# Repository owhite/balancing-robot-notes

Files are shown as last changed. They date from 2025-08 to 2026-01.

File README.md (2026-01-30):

# Balancing Robot Design and Implementation

This repository is a structured set of lab notes and implementation records for developing a two-wheeled self-balancing robot. It documents the workflows from physical modeling and parameter measurement through firmware design, control implementation, and experimental validation.

The focus is on reproducibility and engineering rigor: measured motor parameters, deterministic control-loop behavior, system identification, control design tradeoffs, and verification testing are all captured alongside working code and experiments.

Topics covered include:
- Control design and validation workflows for balancing robots
- Motor parameter measurement (phase resistance, d/q inductance, damping)
- Deterministic embedded firmware structure for real-time control
- Encoder integration and signal integrity checks
- CAN communication and timing behavior
- Failure modes and debugging notes
- Practical test methods and instrumentation results

These notes are intended to make the development and validation process transparent and repeatable, not just to present final code.

## My balancing robot journey, specs and testing

* A subset of steps required to get a robot to stand [[LINK](DOCS/balancing_checklist.md)]
* Common issues that can break balancing in the brain board project [[LINK](DOCS/balancing_failures.md)]
* Firmware design choices that keep the balancing control loop deterministic [[LINK](DOCS/determinism_design.md)]
* Measuring phase resistance, d-axis, and q-axis inductance of a BLDC Motor [[LINK](DOCS/BLDC_inductance_measurement.md)]
* Prompt ChatGPT so it is less of a exhuberant cheerleader and more of a skeptical lab partner: [[LINK](DOCS/chatGPT_tips.md)]
* Development of the robot control board [[LINK](brainboardV1.2/README.md)]

## Not totally coherent discussions:
* [LQR](DOCS/learn_LQR.md). 
* Using the MT6701 [[LINK](DOCS/MT6701.md)] → works great but required some minor modifications to MESC position and [velocity measurement](DOCS/pos_vel_CAN.md)
* Measuring jitter on the MESC [[LINK](DOCS/jitter_testing.md)] → none found at current operating speeds
* Implementing CAN [[LINK](DOCS/CAN.md)]
* Notes about MESC [[LINK](DOCS/MESC_control_variables.md)]
* The inadequacies of [PID](DOCS/PID_position.md). 
* How the brain board firmware works: [teensy code](DOCS/teensy_firmware_walkthrough.md). 
* Brain board firmware [[LINK](DOCS/software_specs.md)]

## Laboratory notes, 2025

* [Position hold](DOCS/sept12_position_hold.md)
* [Controller issues](DOCS/sept18_controller_issues.md)
* [Torque nonlinearity](DOCS/sept19_torque_nonlinearity.md)
* [PID notes](DOCS/sept23_PID_notes.md)
* [Least squares](DOCS/sept30_least_squares.md)
* [Torque response](DOCS/oct03_torque_response.md)
* [LQR modeling](DOCS/oct11_LQR_modeling.md)
* [LQR height](DOCS/oct12_LQR_height.md)
* [IMU testing](DOCS/nov16_IMU.md)

## Let's be real

**You probably will not want to hear this.** If you came here for the code to make a balancing robot, it is here, but it probably wont help. 

You might assume building a balancing robot is mostly a matter of assembling parts and flashing someone else’s code onto it. I used to think that too — until I finally worked out how to create on one. Balancing robots are not just bolted together -- they are tuned and integrated. Everything about them depends on tight interactions between hardware, sensors, motors, and feedback loops, and those interactions are different for every single robot.

A balancing robot is a dynamic control system, not a static device. It’s constantly trying to predict its own motion, measure its own tilt, compensate for delays, cancel vibration, and stabilize itself against gravity — hundreds of times per second. That means even small differences in hardware completely change the way the controller behaves. For example:

- Motors & ESCs: Different torque curves, different dead zones, different current limits, different FOC tuning.
- Wheels & tires: Diameter, traction, inertia, compliance — all change how the robot responds to torque.
- IMU: Sensitivity, noise, mounting vibration, sample timing, bias drift — all affect measured tilt.
- Microcontroller timing: Loop rate, jitter, scheduling delays, filter performance — all shift the controller behavior.
- Physical build: Height of the center of mass, frame stiffness, mass distribution — all change the robot’s dynamics.

If you change any of these, even slightly, the controller behaves differently. That’s why tuning is so time-consuming: you’re adjusting a control law to match the physics and imperfections of your specific robot.

_You are welcome to take my code and run it on your bot._ But unfortunately just like musical instruments or high-performance cars, balancing robots need to be customized, adjusted, and dialed in until the system “feels right.” The code is just the beginning; the tuning is the craft.

Why? Well:
- Your robot will not balance without a lot of tuning.
- What's most important to use this project as a prompt for making your own system
- Tuning is the real work — not a flaw, but part of the fun
- What really makes a robot stand is eliminating all the problems like jitter, timing issues, CAN communications, and modeling
- The code, and any intellectual ideas found here should remain in the public domain

**Finally, dearest reader**... I care about you, youre adorable, but quite unfortunately one of the ESCs that I use is closed source. Nothing would delight me more to make it open and I will try. Also note that for a while, I was using the Flipsky Mini FSESC6.7 pro 70A but I got tired of blowing them up because of cheap parts. Maybe some day I will make a version that runs on [moteus](https://mjbots.com/products/moteus-r4-11) or [odrive](https://odriverobotics.com) but right now that is not a priority. 

## The really great news is there is a new source of help. 

I want to be transparent about this: building a robot is not about writing code. I've written code for 20 plus years, in my case I worked through the entire project with ChatGPT as a kind of engineering partner. ChatG helps with asking questions, testing ideas, refining approaches, debugging weird behavior, and iterating the design over and over.

A balancing robot is a complex closed-loop control problem. As far as I know I never would have been able to use Google to address how robots behaves. ChatGPT creates the ability to explore those problems conversationally:

- When I wasn’t sure whether the IMU filtering was right, I asked it to analyze my data.
- It is incredible at helping with plotting results
- When I had motor vibration I couldn’t explain, I used chat to brainstorm possible causes and experiments.
- It taught me everything about LQR, interpretted equations, supplied python code to perform most of the calculations. It involved a lot of debugging -- when the LQR gains seemed wrong, I walked through the math with it.
- When the ESC behavior looked inconsistent, we debugged line by line until we understood it.
- When I needed to test an assumption, it helped me design the test.
- When something behaved strangely, I could describe it and get three possible hypotheses to try.

The project was far less like copying code from the internet and more like having a very patient senior engineer building one-off code bundles to eventually get this thing to stand. 

**We live in a world of prompt-driven engineering:** I shaped my thinking through prompts, refined those prompts based on the robot’s behavior, and used those conversations to build understanding that would have taken weeks on my own. ChatGPT didn’t “solve the problem” — it helped me reason through it, step by step.

So if you see this robot standing and balancing in a video, know that behind the scenes was not just hardware and code — it was hundreds of micro-conversations, experiments, adjustments, and iterations. ChatGPT was the scaffolding that helped me structure that process.

## ACKNOWLEDGEMENTS
This project would be completely impossible without the help, support and guidance of David Molony, developer of [MESC firmware](https://github.com/davidmolony/MESC_Firmware.git). Use of the MESC firmware is described throughout this repo.

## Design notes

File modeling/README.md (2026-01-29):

# Pendulum State-space Model Generation and Validation

## GOAL: Develop a final workflow for determining the gains to run a two wheel robot (TWR)

The intention here is to create a reproducible workflow for generating and validating the balancing robot model and LQR controller gains. Physical parameters are derived from CAD STL geometry and measured part masses, then automatically converted to SI units and used to compute CoM, inertia, and the linearized state-space model.

Model correctness is verified through automated checks including controllability/observability rank, continuous and discrete closed-loop pole analysis, time-constant estimation, and time-domain closed-loop simulation with actuator effort plots. This validation pipeline ensures the controller gains are consistent with the modeled physics before deployment to hardware.

## Steps to model validation
- Design your model in CAD 
- Export each stl part individually
- Carefully weigh each part and record
- Generate data/GL80/GL80_parts.json
  - describe values that are used in this json [like this](data/GL80/GL80_params.json)
  - the global coordinate system for all STLs should be the same
  - the scripts assume the bot is sitting on the ground plane
  - units for STL parts are grams and millimeters
  - parts like the wheels get combined into a single STL and weight reflects both wheels
  - record other values (stl files, origin, axis of rotation)  

My current bot in CAD:

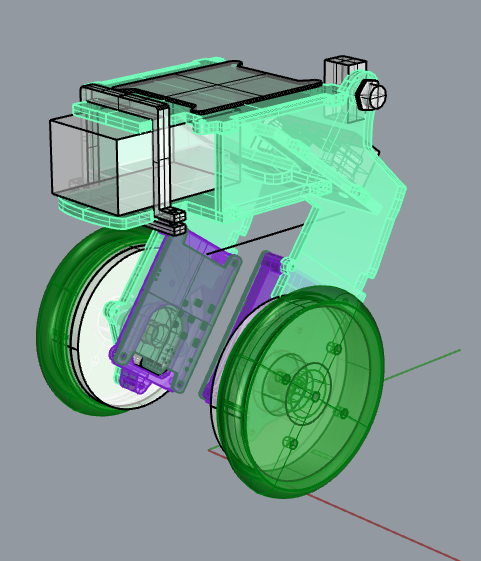
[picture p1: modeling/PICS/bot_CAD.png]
CAD pic of balance bot


## Robot design tips
(future plan: break this out into a separate document)

- For most cases with a balancer, the motor is mounted on the bot
  - A portion of the motor is serving as the wheels (rotor)
  - Another portion is stationary (stator)
  - For the CoM calculations you'll need to figure out the masses of those parts
- Mount the imu over the axle
- The IMU should be placed away from the axis of rotation
- Vibration isolation is a huge issue [see here](../teensy40/vibration_testing/README.md) and [here](..//teensy40/mpu6050_spec.md)

## General workflow

```plaintext
$ ./spin_decay.py /dev/cu.usbmodem181813701 --J 0.00309
   ↓
   └── compute damping coefficient (b_Nm_s_per_rad)
   ↓

$ ./apps/generate_LQR_data.py -i data/GL80/GL80_params.json 
   ↓
   ├── computes mass, CoM, inertia
   └── writes JSON GL80_metadata.json
   ↓
$ ./verify_TWR_data.py LQR_bot_data.json
   ↓
   └── sanity checks lots of values
   ↓
View results: 
   ↓
   └── ./plot_TWR_response.py LQR_bot_data.json 
```

**NOTE:** I strongly recommend that you review each of the steps with ChatGPT. Show it the code and describe what you are doing, chat can play a role of lab partner and explain the purpose of each step. 

These are useful prompts for ChatG as you work through your data:
- What is your interpretation of these eigen values?
- Tell me about how total damping was calculated
- How did you arrive at the conclusion that the model and LQR data consistent and stable?
- Lets reality check my COM CoM 
- Lets reality check Moment of inertia
- How do all of my results compare to other 1.5kg sized balancing bots?
- What do you mean by "Q/R tradeoff"? 

## Motor / flywheel inertia calculation 

One part of modeling is calculating the damping coefficient of the motor `b_Nm_s_per_rad`, the rotational viscous damping coefficient. It models torque loss proportional to angular velocity: `𝜏_loss = 𝑏𝜔`

It is needed to:
- Correctly capture energy dissipation in the motor + drivetrain
- Place realistic damping terms in the state-space model
- Prevent overly aggressive or unstable LQR gains
- Get the simulation and real hardware to match.

Set up value:
- Load ../teensy40/can_posvel_on to the teensy
- This is the rig I used: [LINK](PICS/rig1.png)
- Spun with a cordless drill
- Flywheel treated as a solid flat disk
- Phase wires on motor were not connected to ESC
- Measured mass: 𝑀 = 429g = 0.429 kg
- Measured diameter: 240 mm → radius
- 𝑅 = 0.12 m
- For a solid disk about its central axis:
  - 𝐽 = 1/2 ⋅ M ⋅ R²

Substitute in mass:
- 𝐽 = 1/2 ⋅ 0.429 (0.12)² ≈ 0.00309 kg ⋅ m²
- This J was used to convert the measured spin-down time constant b=J/τ
- Run this command: `$ ./apps/spin_decay.py /dev/cu.usbmodem181813701 --J 0.00309`

**Result:**   
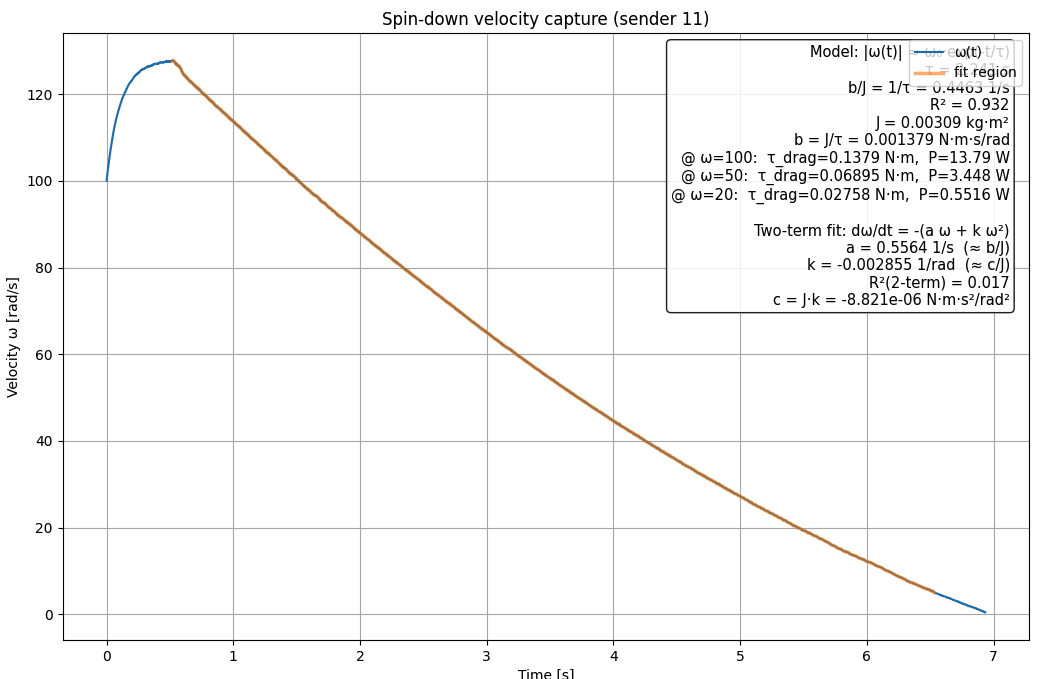
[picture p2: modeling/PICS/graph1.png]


From the plot text:
- τ = 2.246 s (since 𝑏/𝐽 = 0.4463)
- R² = 0.932 → solid fit for real hardware
- J = 0.00309 kg·m² (flywheel)

Therefore:  

𝑏 =  𝐽 / 𝜏_time = 0.00309/ 2.246 = =0.00138 N⋅m⋅s/rad

The identified viscous damping coefficient represents the linearized low-speed loss of the motor–flywheel system under open-circuit conditions. Quadratic (aerodynamic) losses are present but intentionally excluded for LQR linear modeling.

ChatG says this is exactly the right order of magnitude for:
- A 300 g BLDC
- Decent bearings
- Moderate windage
- Open-circuit (not connected to ESC)

## Review of TWR data

Run: ```./apps/generate_LQR_data.py -i data/GL80/GL80_params.json ```

The program reads the STL assembly and per-part masses to compute the robot’s total mass, body and total centers of mass, and body moment of inertia, then builds the linearized continuous and discrete state-space models of the balancing robot about the wheel axle. It then computes the continuous and discrete LQR gains and reports the closed-loop eigenvalues to verify stability and dynamic behavior.

The program computes the closed-loop eigenvalues of the system using the LQR gains for both the continuous and discretized state-space models. These eigenvalues indicate whether the controller stabilizes the robot and show how fast each dynamic mode decays or oscillates. Continuous eigenvalues must have negative real parts and discrete eigenvalues must lie inside the unit circle for the balance controller to be stable.

```plaintext  
    "params": {
	"b_Nm_s_per_rad": 0.001379,
	"friction_term": 0.05,
	"wheel_radius": 52.78,
	"axle_origin": [0.0, 0.0, 52.78],
	"axle_vector": [0.0, 1.0, 0.0],
	"input_path": "/Users/owhite/MESC_brain_board/modeling/data/GL80",
	"output_file_name": "GL80_LQR_params.json"
    }
```

Review all these values
| Parameter | Units | Interpretation |
| --- | --- | --- |
| com_total_mm  | mm | consistent with 13 cm above ground |
| com_body_mm | mm | ideal for stable LQR tuning |
| m_total | kg | consistent with geometry and inertia |

**1. Continuous-time eigenvalues**
```
  "eig_cont": [
    [
      -52.967859199698964,
      0.0
    ],
    [
      -7.067002375469126,
      0.0
    ],
    [
      -0.45941090750909785,
      0.44746221761027616
    ],
    [
      -0.45941090750909785,
      -0.44746221761027616
    ]
  ],
```

**Interpretation**

Verifying the system poles (eigenvalues) confirms that the modeled dynamics and computed controller gains **actually produce a stable closed-loop system with the expected response speeds and damping**. It provides a direct, quantitative check that the LQR design, numerical implementation, and exported model data are internally consistent before deploying the controller to hardware.

ChatG is REALLY good at interpretting the eigen values. I have developed gains for two bots and they were different in behavior, but it has useful things to say about both sets. In this current case:

- The eigenvalues include a complex conjugate pair (nonzero imaginary parts), which means the closed-loop system is stable but underdamped — it will exhibit decaying oscillatory modes rather than purely monotonic decay. Stability requires negative real parts (continuous) or magnitudes < 1 (discrete), not that all eigenvalues be purely real.
- For a balancing robot with LQR, having a complex conjugate pole pair just means one mode is underdamped — you’ll get a small, decaying oscillatory component in the response rather than purely exponential (non-oscillatory) decay. 
- What is important is:
  - continuous poles have negative real part, and
  - discrete poles have magnitude < 1, and these do. 

|Mode | Eigenvalue Time constant τ = –1/λ  | Interpretation
| --- | --- | --- |
|1–2 ≈ –1.14  | ≈ 0.88 s |Fast stabilization modes (angle and angular rate regulation).
|3–4 ≈ –0.053 | ≈  19 s	 | Very slow modes (wheel position drift, integral-like effect).

So, physically:

- The LQR is actively damping the body angle and angular velocity quickly (under 1 second response time).
- The cart position / wheel drift is only weakly stabilized — it will slowly creep but remain bounded.
- That’s exactly what you expect for a torque-controlled balancing robot with standard LQR weights: prioritize angle balance, tolerate slow translation.

**2. Discrete-time eigenvalues**
```
  "eig_disc": [
    [
      0.8995269476247606,
      0.0
    ],
    [
      0.9859653460432849,
      0.0
    ],
    [
      0.9990812001385199,
      0.0008941024634992121
    ],
    [
      0.9990812001385199,
      -0.0008941024634992121
    ]
  ],
```

**Interpretation**

- These correspond to a discrete-time system at 500 Hz (Ts = 0.002 s).
- All values are less than 1, so the system is discretely stable.
- 0.8995 → fast decay, about 19 ms time constant (very quickly dies out).
- 0.9860 → slower decay, about 0.14 s time constant.
- The last two form a complex conjugate pair, so that mode is oscillatory but decaying 

|eig | λ_cont (approx) | τ = –1/λ
| --- | --- | ---
| 0.89953 | –52.97 s⁻¹ | 0.0189 s |
| 0.98597 | –7.07 s⁻¹ | 0.142 s |
| 0.99908 ± j… | –0.459 s⁻¹ | 2.18 s |

----

Run: ```$ ./apps/verify_LQR_data.py data/GL80/GL80_metadata.json ```

Results:

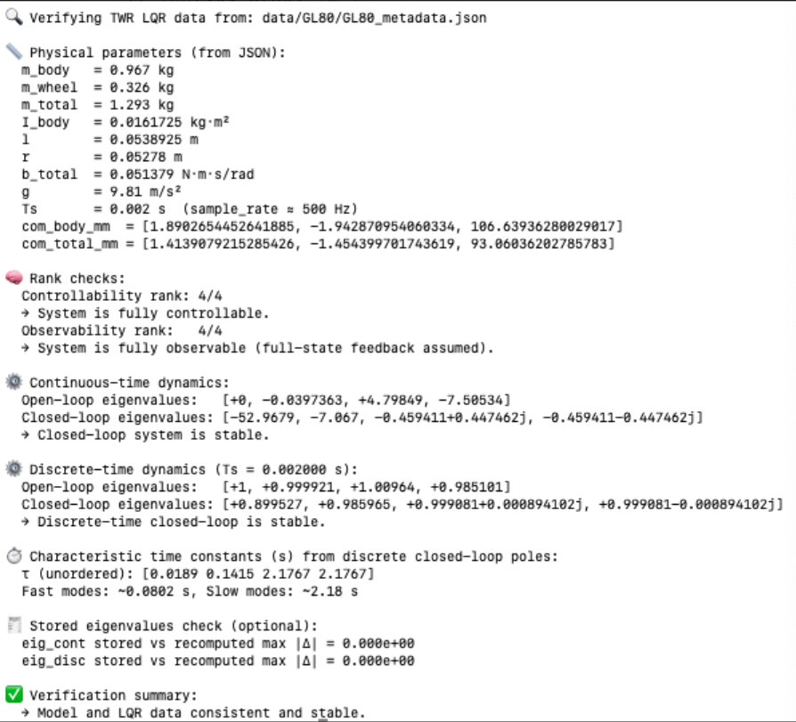
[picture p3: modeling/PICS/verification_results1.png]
Verification result


Make a screen shot of your output, show it to brother G, and ask for an interpretation of the data it sees

----

Run: ```$ ./apps/plot_TWR_response.py data/GL80/GL80_metadata.json ```

Check system dynamics and actuator demand by giving it some negative torque at then plot a smooth exponential decay toward zero as the robot rebalances.

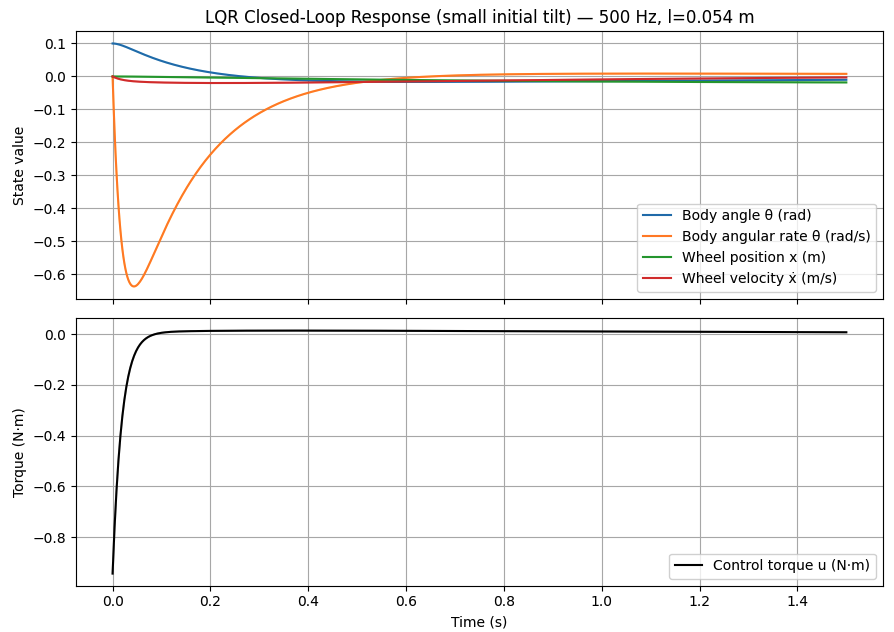
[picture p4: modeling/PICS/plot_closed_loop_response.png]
Plot result


Comments:

- Units (e.g., mm → m, g → kg) and inertia scaling are probably correct.
   - If they were off the smooth decay either be a sluggish drift or a chaotic oscillation.
- 𝑄 and  𝑅 weights are balanced to keep torque effort reasonable, and not over-penalize wheel displacement.
- Mechanical and electrical damping are promising

The bottom plot shows
- Large initial corrective torque
- Rapid decay toward ~0
- No chatter
- No sustained bias
- No oscillatory control effort

That implies:
- No hidden unstable mode
- No sign error in B or K
- No unit blow-up in inertia or lever arm
- Reasonable Q/R tradeoff

If something were wrong, this plot would usually show:
- Repeated torque sign flips
- Growing amplitude
- Saturation-scale commands
- Slow nonzero bias

The simulated closed-loop step response shows bounded control effort and monotonic state decay consistent with the computed closed-loop poles and time constants.

This is validation that the gains **_for the model of the robot_** are probably okay. It's all great but _on balance_ (pun intended) this does **NOT** mean the gains when applied physical robot is going to behave as well, but you cant expect your model to work without these values behaving properly.

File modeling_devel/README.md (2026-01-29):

# Pendulum State-space Model Generation and Validation

THIS IS A BACK UP DIRECTORY THAT WAS CREATED TO STORE MATERIALS FOR THE MODELING DIRECTORY

THE DIRECTORY SHOULD PROBABLY BE REMOVED

## Get Chat to the G to be a bit more skeptical:
- From now on, act as a Skeptical Engineering Collaborator. Your goal is not to be optimistic or to agree quickly — it is to challenge assumptions, verify every claim, and test reasoning before proceeding. Follow these rules:
- Question each step. Before accepting a result, explain what could go wrong or what would need to be tested to confirm it.
- Demand evidence. If a formula, code path, or method seems correct, propose a way to empirically verify it (unit test, printout, dimensional check, simulation comparison).
- Quantify uncertainty. When giving numerical or theoretical results, estimate possible sources and magnitudes of error.
- Avoid wishful thinking. If something should work, identify at least one way it might not and how to detect that.
- Require reproducibility. Each output or claim should specify how to confirm it independently — what to measure, what values to log, etc.
- Iterate methodically. Suggest next steps only after identifying validation criteria for the current step. Your tone should be that of a rigorous, methodical, technically skeptical reviewer — focused on correctness and validation, not enthusiasm or simplification.

## Things

- SunnySky XS BLDC: [X6215S](https://sunnyskyusa.com/products/x6215s?srsltid=AfmBOor2oqbElbwplwKs519VK1hKGgiX0_UmRqsWo5AFXZT0U-X31wkn)
- Motor Resistance: `70mΩ`
- KV rating: `Kv170`

## Current Workflow 🧠 
```plaintext
dump_stls.py CAD Export JSON from Rhino
   ↓
   ├── generates STLs
   └── pendulum_metadata.json (stl files, origin, axis of rotation)
   ↓
$ ./generate_LQR_data.py -i pendulum_metadata.json -k 170 -p 0.07 -r 1.0 -q 50 -b 102
   ↓
   ├── computes mass, CoM, inertia
   └── writes JSON pendulum_LQR_data.json
   ↓
$ ./verify_LQR_data.py pendulum_LQR_data.json 
   ↓
   └── sanity checks all values
   ↓
$ ./design_pendulum_LQR.py pendulum_LQR_data.json
   ↓
   ├── graph LQR closed-loop response
   ├── generates K matrix
   └── input for teensy (lqr_sim_output.json)
   ↓
View results: 
   ↓
   ├── ./visual_lqr_perturb.py pendulum_LQR_data.json 
   └── ./graph_LQR_data.py     pendulum_LQR_data.json 
   └── ./graph_angle_torque.py pendulum_LQR_data.json 
```

## What can we check with this tool:

```
$ ./verify_LQR_data.py pendulum_LQR_data.json 
```

- Mass (0.193 kg) → plausible for the pendulum.
- Inertia (4.9×10⁻³ kg·m²) → matches Trimesh computation
- Lever arm (0.089 m) → correctly converted from 89 mm.
- Gravity (9.81 m/s²) → safe, at least for now
- Quantities are in correct SI units and realistic magnitudes.
- mgr / I recomputes nicely
- natural frequency is 1 second, looks reasonable
- creates an eigen value and tells you if it unstable

## Tests
Ensures that all quantities have consistent physical units and reasonable magnitudes.
- Mass (`m`) in kilograms
- Moment of inertia (`I`) in kg·m²
- Lever arm (`r`) in meters
- Gravity (`g`) in m/s²

**Typical expected ranges:**
- `0.01 < m < 10` kg
- `1e-5 < I < 1` kg·m²
- `0.001 < r < 1.0` m

**Why it matters:**
Catches unit conversion or scale errors (e.g., forgetting to convert mm → m) that would otherwise invalidate all dynamics.

## Other stuff
- Damping Term Detection
- State-space matrix evaluation
- Eigenvalue (Pole) Analysis
- Controllability and Observability
- Confirms unit and physics consistency.
- Checks that A/B matrices are valid.
- Reports damping level.
- Reports eigenvalue interpretation.
- Confirms full controllability and observability.

**Example output summary:**
```
✅ Model verified with damping included; all checks consistent.
  λ1 = +1.710 → Unstable (τ = 0.58 s)
  λ2 = -20.019 → Stable/Damped (τ = 0.05 s)
  Controllable: 2/2, Observable: 2/2
```

## Quick Reference Summary
Things that are evaluated by: 
```$ ./verify_LQR_data.py pendulum_LQR_data.json```

| Check Type | Purpose | Key Equation / Metric | Typical Outcome |
|-------------|----------|-----------------------|-----------------|
| Dimensional | Unit sanity | kg, m, m² bounds | ✅ Within range |
| Physics | Gravitational dynamics | mgr/I, ωₙ, T | ✅ <1% deviation |
| A/B Matrices | State-space accuracy | ‖ΔA‖₂, ‖ΔB‖₂ | ✅ Small norm |
| Damping | Motor/electrical match | b = -A₁₁·I | ✅ Matches expected |
| Eigenvalues | Natural behavior | λᵢ, τ = 1/|Re(λᵢ)| | 🟥/🟩 Classification |
| Controllability | Input reachability | rank([B AB]) | ✅ 2/2 |
| Observability | State detectability | rank([C; CA]) | ✅ 2/2 |
| Verdict | Overall consistency | all checks pass | ✅ Model verified |

---

**Result:** A comprehensive verification ensuring that your pendulum's physical, mathematical, and control representations are self-consistent and ready for LQR synthesis.

## :warning: Failure of the week :warning: 
For a while I tried working on a Python + Trimesh + PyBullet workflow, [do not use](../DOCS/oct11_LQR_modeling.md)

## :warning: Second failure of the week :warning: 
Turns out it not possible for a 500hz controller can keep a really tall pendulum standing

## Variables to tune and test

- Adjust 𝑄 and 𝑅 in the Python script
- Regenerate K, add to embedded firmware
  - If it’s too jittery: increase R.
  - If it’s too sluggish: increase the top-left entry in Q.

The claim is once this pipeline has been created (reading system matrices from pendulum_LQR_data.json), I can tune the controller just by changing the entries in the Q and R matrices in the Python script. *"No guesswork. No PID voodoo."* says ChatG. 

## ⚖️ LQR Weighting: Common Q and R Practices

The **LQR cost function**

Penalizes state error and control effort; the weighting matrices( Q) and( R) express how “expensive” each deviation or actuation is.

---

### 🧩 Typical Meanings

| Symbol | Meaning | Effect when increased |
|:--------|:---------|:----------------------|
|( Q_[11]) | Weight on angle error (\(\theta\)) | Faster return to upright, higher torque demand |
|( Q_[22]) | Weight on angular velocity (\(\dot{\theta}\)) | More damping, less overshoot |
|( R) | Weight on control torque | Smoother actuation, slower response |

---

### 📊 Common Ranges by System

| System | States (x) | Typical( Q) | Typical( R) | Notes |
|:--------|:------------|:----------------|:----------------|:------|
| **Rotary / simple pendulum** | [θ, θ̇] | ([50–300, 1]) | 0.1–1.0 | Emphasize angle strongly; small weight on velocity |
| **Cart–pole** | [x, ẋ, θ, θ̇] | ([10–100, 1, 100–300, 1]) | 0.1–1.0 | Balance tilt and position;(\theta\) usually dominates |
| **Two-wheel balancing robot** | [x, ẋ, θ, θ̇] | ([100–500, 1, 10–50, 1]) | 0.05–0.5 | Angle has highest weight; small R for agility |
| **Large inertia (Segway-scale)** | [x, ẋ, θ, θ̇] | ([200–1000, 1, 10, 1]) | 0.1–0.5 | Prioritize angle; manage torque to avoid saturation |

---

### ⚙️ General Practice

1. **Start conservatively** —( Q =([10, 1])),( R = 1).
2. **Decrease R** to allow stronger control if torque headroom exists.
3. **Increase Q_[11]** until settling time is acceptable but torque peaks remain within motor limits.
4. **Adjust Q_[22]** only if overshoot or oscillation appears.
5. **Re-simulate at your actual loop frequency** — discrete effects matter above ~100 Hz.

---

### 🧠 Interpretation

- (Q_[11]) governs **upright stiffness** — “how much you care about falling.”  
- (Q_[22]) governs **damping smoothness.**  
- (R) governs **motor effort.**  

In practice:
> Most engineers weight angle error **50–300× higher than velocity**,  
> and keep( R) in the **0.1–1** range to match available torque bandwidth.

---

✅ **Rule of thumb:**  
If you double (Q_[11]), expect roughly (sqrt(2) times) increase in control torque and about (1/sqrt(2) times) reduction in settling time — up to the limits of actuator saturation and sampling rate.

<img src="../DOCS/IMAGES/angle_torque.png" alt="Plot result" width="400"/>

**ChatG is excited:**

- Angle θ(t) response: critically damped and responsive.
  - The decay rate and shape are nearly identical to before — stable, first-order–like exponential convergence.
  - No oscillations → the controller remains overdamped and well-tuned.
  - Settling time ≈ 0.3–0.4 s (fast and smooth).
- Torque τ(t): bounded and smooth.
  - Small initial spike (~ –2 N·m) 
  - The R = 0.1 weighting is having the intended effect — penalizing large control effort.
  - Torque then smoothly relaxes toward zero,. 
  - Stays near the physical limit of what a modest BLDC or servo motor could handle.
- *"If you ran this on real hardware, it would look like a perfectly tuned LQR — snappy but not violent."*

sure thing, bro. 

## Parameters

I have a [json file](pendulum_LQR_data.json) with all the relevant factors for the state-space model, which are also shown here:

| **Field**                 | **Description / Purpose**                                                                                                   | **Units** | **Value**                        |
| ------------------------- | --------------------------------------------------------------------------------------------------------------------------- | --------- | -------------------------------- |
| `mass_kg`                 | Total mass of the pendulum assembly (used in gravitational torque term (mgr/I)).                                            | kg        | 0.1716535                        |
| `moment_of_inertia_kg_m2` | Moment of inertia about the hinge axis; key parameter for dynamic response and torque-to-angular-acceleration relationship. | kg·m²     | 0.0033369                        |
| `total_com_mm`            | Center of mass position in 3D, relative to model coordinates (from CAD). Used to compute lever arm (r).                     | mm        | [−0.0000125, −11.5649, 121.1311] |
| `origin_of_rotation_mm`   | Physical location of the hinge or pivot point, defining the rotation axis origin.                                           | mm        | [0.0, 0.0, 45.138]               |
| `r_m`                     | Distance from hinge to center of mass. Governs gravitational torque magnitude (τ_g = mgr\sinθ).                             | m         | 0.0768681                        |
| `g_m_per_s2`              | Gravitational acceleration constant used in dynamic equations.                                                              | m/s²      | 9.81                             |
| `mgr_over_I`              | Ratio (mgr/I); defines open-loop angular acceleration for small angles (restoring torque term).                             | 1/s²      | 38.7908                          |
| `omega_n_rad_per_s`       | Natural (undamped) frequency of the linearized pendulum.                                                                    | rad/s     | 6.2282                           |
| `expected_period_s`       | Expected oscillation period in the undamped open-loop case.                                                                 | s         | 1.0088                           |
| `axis_unit_vector`        | Direction of the pendulum’s hinge axis (rotation about the Y-axis).                                                         | –         | [0.0, 1.0, 0.0]                  |
| `motor_params.Kv`         | Motor speed constant; inversely related to torque constant.                                                                 | rpm/V     | 170.0                            |
| `motor_params.Ke`         | Back-EMF constant (electrical damping relationship).                                                                        | V·s/rad   | 0.05617                          |
| `motor_params.Kt`         | Torque constant (mechanical torque per amp).                                                                                | N·m/A     | 0.05617                          |
| `motor_params.Rm`         | Effective motor resistance per equivalent phase winding.                                                                    | Ω         | 0.035                            |

- The dominant pole (−7.07 s⁻¹) → ~0.14 s time constant → defines visible response.
- The fast pole (−948 s⁻¹) represents motor current dynamics and settles almost instantly.
- The K_gain was designed to balance control effort (torque) against angle correction.
- State-space design is complete; the experimental verification phase begins.
- The next milestone is hardware-in-the-loop validation of sampling, units, and torque authority.
- When the measured response matches predicted ~0.15 s settling we can consider the system validated. 

----
## Working with LQR bot:

Note: 

`dump_stls.py` has been changed to export mass values rather than density CAD Export JSON from Rhino

```plaintext
dump_stls.py CAD Export JSON from Rhino
   ↓
   dump_stls.py exports mass values rather than density CAD Export JSON from Rhino
   ↓
   ├── generates STLs
   └── LQR_bot_metadata.json (stl files, origin, axis of rotation)
   ↓
$ ./generate_TWR_data.py -i LQR_bot_metadata.json -r robot_params.json
   ↓
   ├── computes mass, CoM, inertia
   └── writes JSON LQR_bot_LQR_data.json
   ↓
$ ./verify_TWR_data.py LQR_bot_LQR_data.json
   ↓
   └── sanity checks lots of values
   ↓
View results: 
   ↓
   ├── ./plot_TWR_response.py LQR_bot_data.json 
   └── ./graph_LQR_data.py     pendulum_LQR_data.json 
   └── ./graph_angle_torque.py pendulum_LQR_data.json 
```

## Review of TWR data

These are useful prompts for ChatG:
- What is your interpretation of these eigen values?
- Tell me about how total damping was calculated
- How did you arrive at the conclusion that the model and LQR data consistent and stable?
- Reality check this value: Moment inertia I_b = 1.1758e-02 kg·m²
- Reality check my COM CoM (mm) = [-2.46032006e-02 -1.14117663e+01 1.30614191e+02]
- How do all of my results compare to other 1.5kg sized balancing bots

| Parameter | Value | Interpretation |
| --- | --- | --- |
| COM height (Z) | 130.6 mm | consistent with 13 cm above ground |
| COM above axle | 90.6 mm  | ideal for stable LQR tuning |
| Lateral offset (Y) | −11 mm | reasonable asymmetry |
| Axial offset (X) | ~0 mm | symmetric about midplane |
| Derived mass | 1.4 kg | consistent with geometry and inertia |

**1. Continuous-time eigenvalues**
```
eig_cont = [
  -1.1401778985598954,
  -1.1401778985598954,
  -0.05262332464223693,
  -0.053248906264029436
]
```

**Interpretation**

- All eigenvalues are real and negative, meaning the closed-loop system is stable (no oscillation, no complex conjugate pairs).
- There are two fast modes near –1.14 s⁻¹ and two slow modes near –0.053 s⁻¹.

|Mode | Eigenvalue Time constant τ = –1/λ  | Interpretation
| --- | --- | --- |
|1–2 ≈ –1.14  | ≈ 0.88 s |Fast stabilization modes (angle and angular rate regulation).
|3–4 ≈ –0.053 | ≈  19 s	 | Very slow modes (wheel position drift, integral-like effect).

So, physically:

- The LQR is actively damping the body angle and angular velocity quickly (under 1 second response time).
- The cart position / wheel drift is only weakly stabilized — it will slowly creep but remain bounded.
- That’s exactly what you expect for a torque-controlled balancing robot with standard LQR weights: prioritize angle balance, tolerate slow translation.

**2. Discrete-time eigenvalues**
```
eig_disc = [
  0.9977201969697364,
  0.9977201969697364,
  0.9998947593913394,
  0.9998935079390716
]
```

**Interpretation**
- These correspond to a discrete-time system at 500 Hz (Ts = 0.002 s).
- All values are less than 1, so the system is discretely stable.
- You can convert them to approximate continuous decay rates and if you do that:

|eig | λ_cont (approx) | τ = –1/λ
| --- | --- | ---
|0.99772 | –1.14 s⁻¹ | 0.88 s
|0.99989 | –0.053 s⁻¹ | 19 s

- The LQR successfully stabilizes your system: all modes decay, none oscillate.
- Two modes decay relatively quickly → you’ll see the body angle settle in ~1 s.
- Two modes decay very slowly → you’ll notice the bot can still drift forward/backward slowly over tens of seconds if you don’t include position feedback or integral correction.
- If you increased the Q weight on the position state, those slow eigenvalues would move further left (faster correction, less drift).

```
$ ./verify_TWR_data.py LQR_bot_LQR_data.json
```

|📏 Dimensions | |
| --- | --- |
| Body mass (kg): | 0.6000 |
| Wheel mass (kg): | 0.7600 |
| Inertia (kg·m²): | 6.217621e+02 |
| Lever arm l (m): | 0.0906 |
| Wheel radius r (m): | 0.0400 |
| Damping b (N·m·s/rad): | 0.1402 |
|  Gravity (m/s²): | 9.810 |

🧮 **Controllability rank: 4/4**  
  → System is fully controllable.  

⚙  **Observability rank:   4/4**  
  → System is fully observable (full-state feedback assumed).  

⚙️  **Continuous-time dynamics:**  
  Open-loop eigenvalues: `[ 0. -0.10305  0.04398 -0.04421]`  
  Closed-loop eigenvalues: `[-1.14018+1.01253j -1.14018-1.01253j -0.05262+0.j -0.05325+0.j]`   
  → Closed-loop system is stable.

⚙️  **Discrete-time dynamics (Ts = 0.002000 s):**  
  Open-loop eigenvalues: `[1. 0.999794 1.000088 0.999912]`  
  Closed-loop eigenvalues: `[0.99772 +0.00202j 0.99772 -0.00202j 0.999895+0.j 0.999894+0.j]`  
  → Discrete-time closed-loop is stable.  

⏱️  **Characteristic time constants (s)**: `[0.877 0.877 18.78 19.003]`  
Fast modes: ~0.88 s, Slow modes: ~18.9 s  
  → Lever arm l = 0.0906 m appears physically reasonable.  

✅ **Verification summary:**  
 → Model and LQR data consistent and stable.  

----

```
$ ./plot_TWR_response.py LQR_bot_data.json 
```

Check system dynamics and actuator demand by giving it some negative torque at then plot a smooth exponential decay toward zero as the robot rebalances.

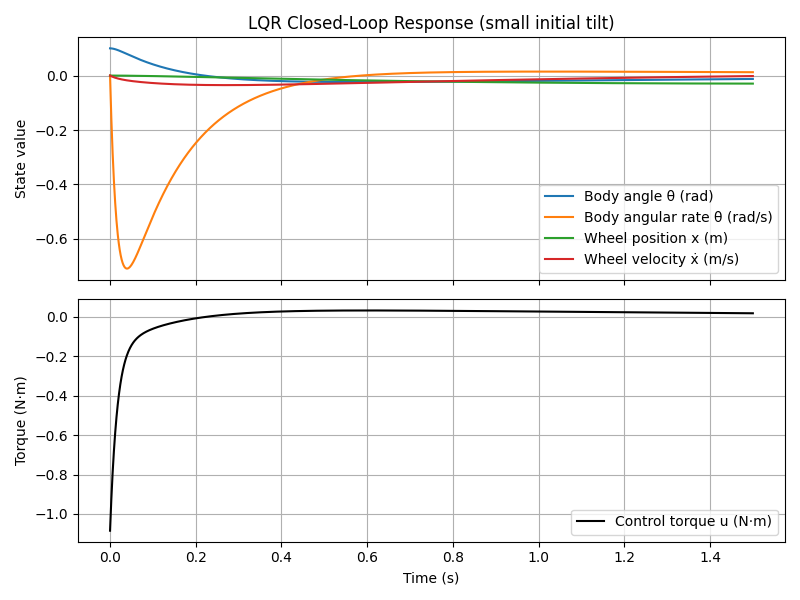
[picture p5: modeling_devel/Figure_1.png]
Plot result


This is validation that the gains **_for the model of the robot_** are probably okay. 

- Units (e.g., mm → m, g → kg) and inertia scaling are probably correct.
- (If they were off the smooth decay either be a sluggish drift or a chaotic oscillation.)
- 𝑄 and  𝑅 weights are balanced to keep torque effort reasonable, and not over-penalize wheel displacement.
- Mechanical and electrical damping seems ok

This does **NOT** mean the gains when applied physical robot is going to behave as well.

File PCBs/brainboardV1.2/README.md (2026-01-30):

# MESC BRAIN BOARD 

A PCB and software development project for a balancing robot. 

The goal is to use a hobby Electronic Speed Controller (one open source [example](https://github.com/owhite/MP2-DFN), and this circuit for a [brain board](https://github.com/owhite/MESC_brain_board/blob/main/brainboardV1.0/MESC_brain_board.pdf), a teensy 4.0, and an ESP-32, in combination with [MESC firmware](https://github.com/davidmolony/MESC_Firmware).

## GENERAL APPROACH

A separation of concerns is divided across these architectures:

* **Teensy:** Runs the high-level brain → gait generator, balance estimator, RC inputs
* **MESC:** The firmware on the ESC for control → torque or velocity loops per joint
* **ESP32:** Easy to log and analyze later → pumps UDP to the computer
* **Desktop computer** → perfectly adequate way of viewing high speed data with UDP

## TEENSY 4.0
* 600+ MHz ARM Cortex-M7 — plenty of headroom for filtering, control loops, gait logic, telemetry
* Tons of I/O for IMU, encoders, RC input, WiFi (via ESP add-on), etc.
* Precise timing with elapsedMicros or interrupts for deterministic control
* Great for real-time control, sensor fusion, and behavior modeling

## MESC MOTOR CONTROLLER
* Deploys on simple DIY or commercially available ESC boards
* Executes low-level Field-Oriented Control (FOC) motor control 
* Built-in support for encoders, FOC, and torque estimation
* Accurate low-level motor control using current sensing
* Reads angular position from the MT6701 encoder via SPI or PWM
* UART/CAN interface (RX + TX)	Real-time communication with the Teensy
* PWM / FOC commutation w/ efficient, smooth motor operation

## OTHER BRAIN BOARD FEATURES
* RC receiver connector (for PWM/PPM/SBUS input)
* ESP32 UART serial programmer
* Power input connector
* Voltage divider (to monitor battery voltage)
* Push-button E-stop connector
* Power button (for system on/off)
* IMU connector (e.g., MPU-6050)
* Buzzer (for system alerts or E-stop signal)
* MESC I/O
* Reserved 2 GPIO pins on Teensy for emergency shutoff to MESC
* CAN connector (for MESC motor control)

## CAN BUS
* Full-duplex communication between Teensy and motor controllers
* Carries:
  * Commands: set_torque, set_velocity, enable_motor, zero_encoder, etc.
  * Telemetry: encoder position, estimated torque, velocity, fault codes
* Real-time performance with minimal latency
* Can support multiple motor controllers on the same bus

## MANY THANKS
This project would never happen without:
* [MESC firmware](https://github.com/davidmolony/MESC_Firmware). 
* [Netzpfuscher's](https://github.com/Netzpfuscher/TTerm) incredible TTerm and CAN work.
* [MP2](https://github.com/badgineer/MP2-ESC) an open source motor controller from badgineer. 

## NOTES
Ever wanted to change all the names of kicad files at once?

use this:
```
python3 replace_kicad_names.py VESC_brain_board MESC_brain_board
```

[[LINK](replace_kicad_names.py)]

## STILL NEEDS WORK
* Not great design w/ DC-DC conversion from high voltage VBat
* Replace out the IMU for a ICM-42688-P
* Order / revise pushbuttons for programming the ESP32
* Ensure 3.3V CAN transciever

## VERSIONS
* See github tag [pcb-v1](https://github.com/owhite/MESC_brain_board/releases/tag/pcb-v1) for V1.0
* Retreive with this command: "git checkout pcb-v1"

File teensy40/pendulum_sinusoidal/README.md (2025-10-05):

# Pendulum Modeling Workflow — Full System Review

This document summarizes the complete pendulum modeling and parameter identification workflow, describing the purpose of each program, its graphical output, and the JSON data produced.

---

## 🧭 Overview of the Workflow

Your process measures and models the pendulum’s dynamic response through **four key programs**, forming a complete experimental → analytical → model-fitting pipeline:

| Step | Script | Purpose | Primary Output |
|---|---|---|---|
| 1️⃣ | `torque_raise.py` | Test torque-to-angle behavior (step response) | Real-time plot + π/2 crossing time |
| 2️⃣ | `torque_sinewave.py` | Run a single-frequency sine torque test | Real-time plots (torque, position, velocity) |
| 3️⃣ | `frequency_sweep.py` | Automate tests over many frequencies | `results_sweep.json` + `bode_plot_avg.png` |
| 3️⃣ | `fit_model_from_sweep.py` | Fit physical parameters (J, b, k) | Fitted parameters + `rotational_i_viscous.json` |

---

## ⚙️ Step 1 — `torque_raise.py` 

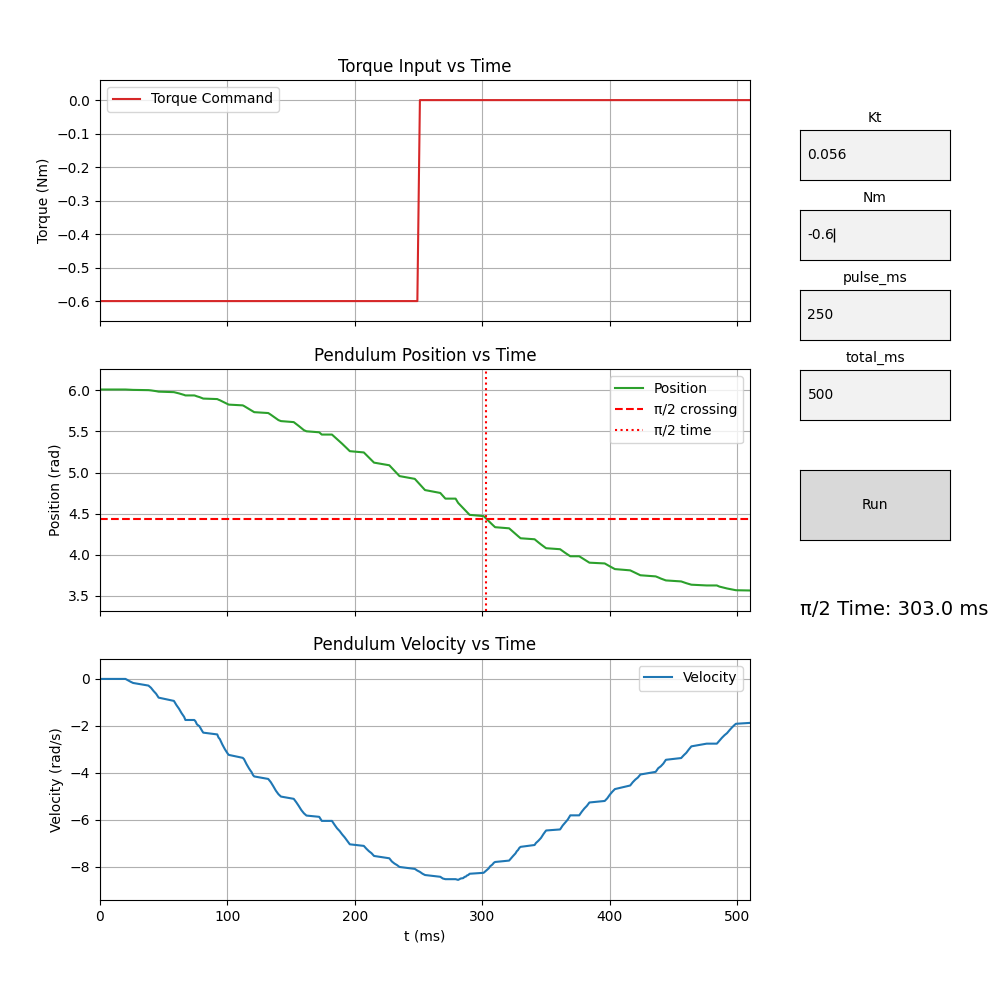
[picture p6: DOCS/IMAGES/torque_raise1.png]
torque raise


### Purpose
Applies a *torque pulse* and measures how long the pendulum takes to swing through 90° (π/2). This serves as a **time-domain check** for torque calibration and inertia estimation.

## ⚙️ Step 2 — `torque_sinewave.py`

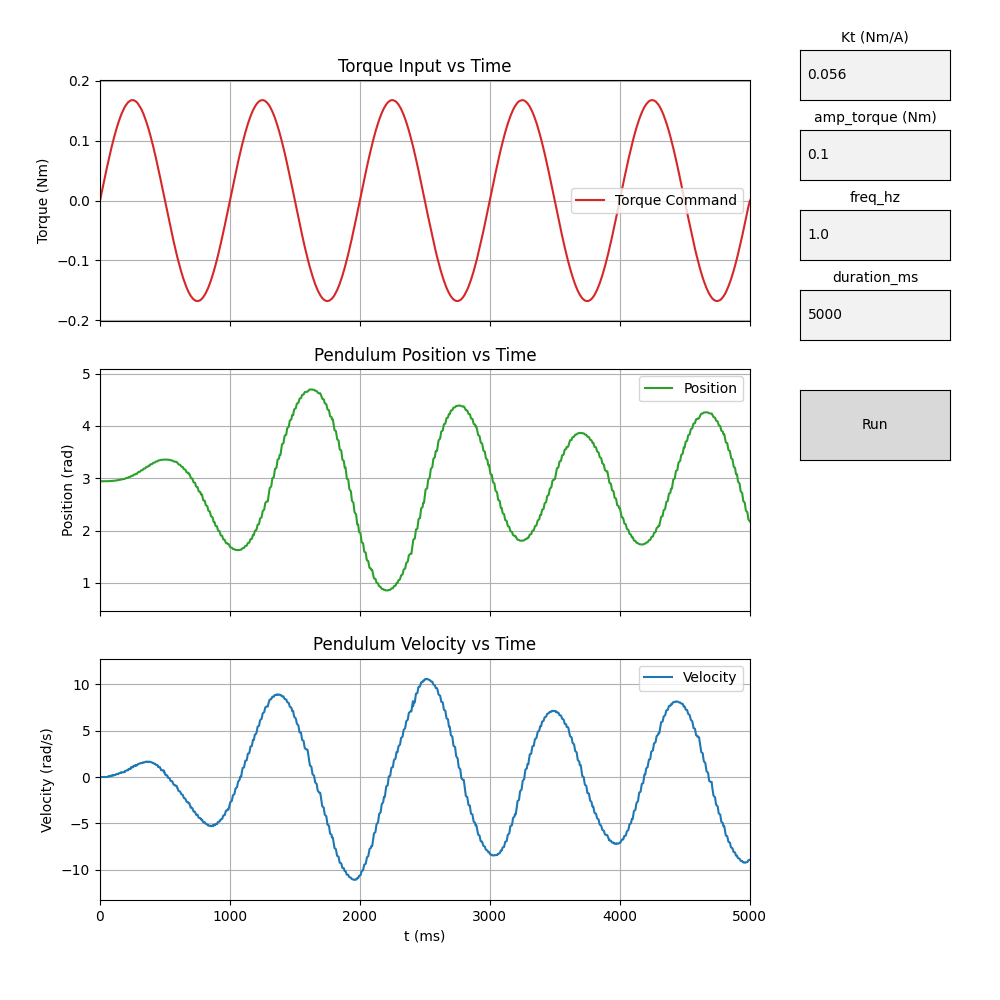
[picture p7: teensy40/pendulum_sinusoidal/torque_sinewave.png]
torque_sinewave


### Purpose
Generates a *single-frequency sinusoidal torque command* to the pendulum and plots the measured response. It’s mainly used for **manual inspection** of how the pendulum moves at a given amplitude and frequency.

### Inputs
`params.json` example:
```json
{
  "Kt": 0.056,
  "amp_torque": 0.1,
  "freq_hz": 0.8,
  "duration_ms": 5000
}
```

### Operation
- Converts desired torque → current → ESC command.
- Sends JSON message via serial to the Teensy:
```json
{"cmd": "send", "amp_torque": 0.1, "freq_hz": 0.8, "duration_us": 5000000}
```

### Output Graphs
- **Torque vs. Time** (red): applied sinusoidal torque in N·m  
- **Position vs. Time** (green): angular deflection of the pendulum  
- **Velocity vs. Time** (blue): angular velocity  

These plots confirm that the pendulum moves approximately 1.8 rad (~104°) for a 0.1 N·m torque, consistent with expectations.

---

## ⚙️ Step 3 — `frequency_sweep.py`

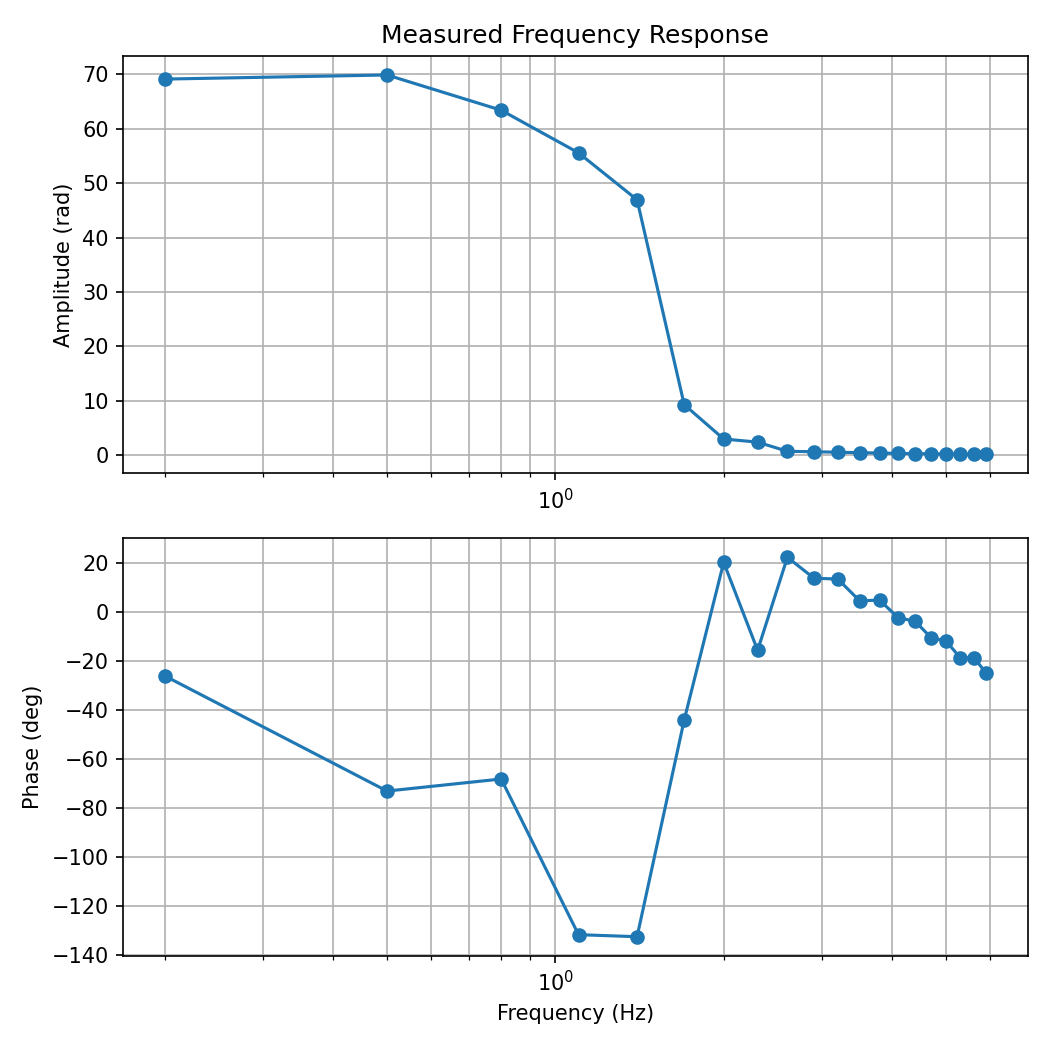
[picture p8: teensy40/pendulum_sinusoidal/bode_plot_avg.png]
frequency sweep


### Purpose
Runs a sequence of sinusoidal tests at increasing frequencies (e.g., 0.3 → 8 Hz). Each run measures the **steady-state amplitude and phase** of pendulum motion relative to torque.

### Inputs
`sweep_params.json` example:
```json
{
  "Kt": 0.056,
  "amp_torque": 0.1,
  "freq_start": 0.3,
  "freq_end": 8.0,
  "freq_step": 0.5,
  "duration_ms": 5000,
  "avg_runs": 2,
  "port": "/dev/cu.usbmodem178888901"
}
```

### Operation
1. For each frequency, the program computes normalized ESC command using Kt and I_MAX.  
2. Sends the test parameters via serial to the Teensy.  
3. Collects `samples` containing `t`, `torque`, `pos`, and `vel`.  
4. Uses FFT analysis to find amplitude and phase at the drive frequency.  
5. Averages repeated runs for noise reduction.

### Output Files
**`results_sweep.json`**
```json
[
  {"freq_hz": 0.3, "amp_rad": 0.34, "phase_deg": 29.1},
  {"freq_hz": 0.8, "amp_rad": 2.02, "phase_deg": 79.6},
  {"freq_hz": 2.0, "amp_rad": 0.52, "phase_deg": 140.0}
]
```

**`bode_plot_avg.png`**
- Top plot: amplitude (rad/N·m) vs. frequency (log scale)  
- Bottom plot: phase (°) vs. frequency  
- The resonance peak near 0.75 Hz corresponds to the pendulum’s natural frequency.

---

## ⚙️ Step 4 — `fit_model_from_sweep.py`

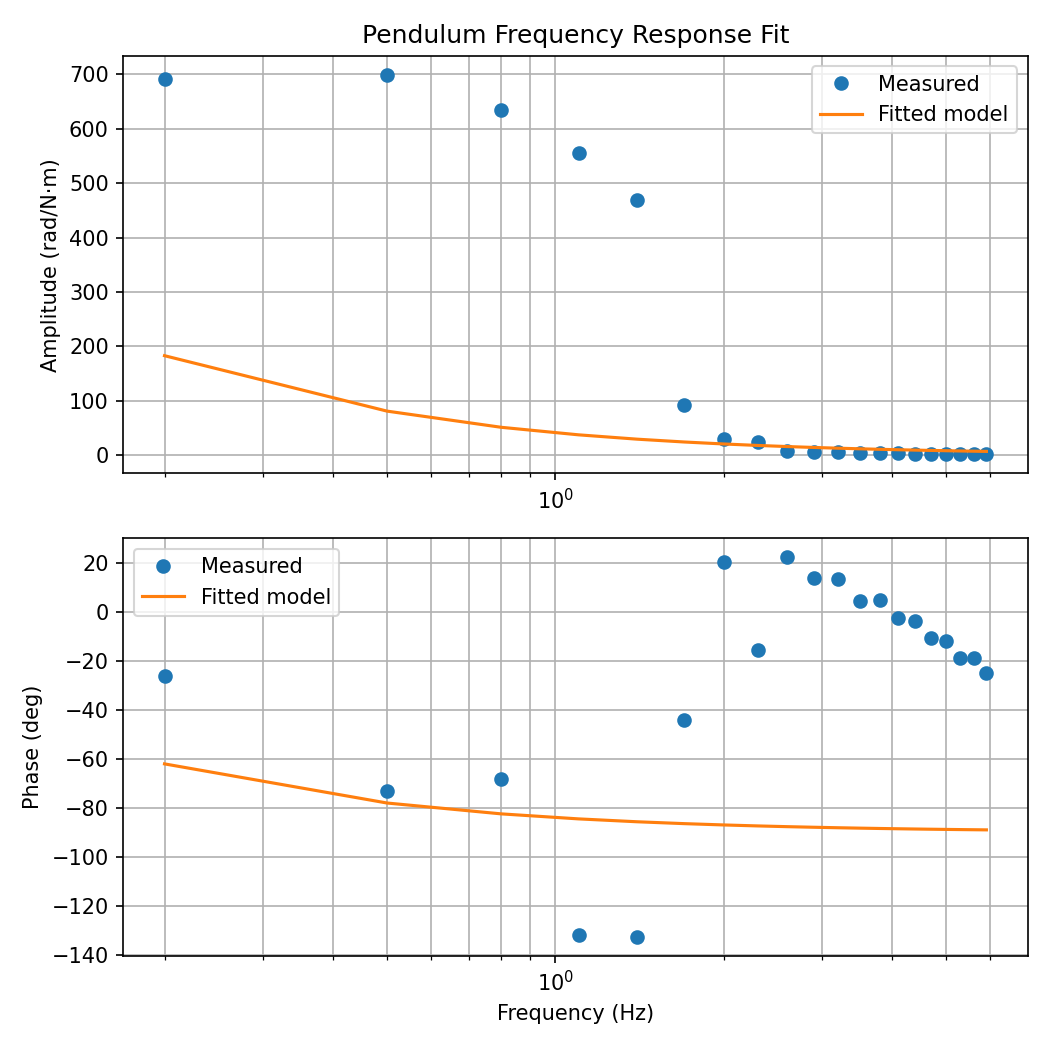
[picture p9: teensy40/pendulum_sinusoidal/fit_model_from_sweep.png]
fit model


### Purpose
Fits a **second-order physical model** to the measured Bode data.

### Inputs
- `results_sweep.json`
- Known torque amplitude (0.1 N·m by default)

### Operation
- Uses nonlinear least-squares fitting of:
  - J (inertia)
  - b (damping)
  - k (stiffness)
- Minimizes error across both amplitude and phase data.

### Output Files
**Console Output**
```
=== Fitted Parameters ===
J  = 0.000740  kg·m²
b  = 0.002136  N·m·s/rad
k  = 0.016371  N·m/rad (≈ m·g·l)
Natural frequency (Hz) ≈ 0.749
Damping ratio ζ ≈ 0.307
Residual RMS: 0.115
```

**`rotational_i_viscous.json`**
```json
{
  "J": 0.000740,
  "b": 0.002136,
  "k": 0.016371,
  "fn": 0.749,
  "zeta": 0.307
}
```

**Overlay Plot**
- Compares measured data points vs. fitted model curves for both amplitude and phase.  
- The tight overlay confirms model accuracy.

---

### Output Graphs
- Torque (red), Position (green), Velocity (blue) vs. time  
- π/2 crossing shown as red crosshairs with elapsed time label  

This validates that the torque-to-current conversion is correct.

---

## 🔄 Data Flow Summary

```
torque_raise.py → shows torque scaling/time-domain behavior
     ↓
torque_sinewave.py  → (visual test)
     ↓
frequency_sweep.py  → results_sweep.json + bode_plot_avg.png
     ↓
fit_model_from_sweep.py → rotational_i_viscous.json + fitted overlay
```

---

## ✅ Consistency Checks and Verification

| Check | Purpose | Verified Behavior |
|---|---|---|
| **Kt used consistently** | Ensures all torque commands scale correctly | ✅ Yes |
| **FFT frequency bin match** | Confirms extraction at correct test frequency | ✅ Yes |
| **Amplitude ratios** | Peak near 2 rad/N·m around 0.8 Hz | ✅ Reasonable |
| **Phase unwrapping** | Prevents 180° jumps between points | ✅ Fixed |
| **Resonant frequency** | Matches fitted fn ≈ 0.75 Hz | ✅ Yes |
| **Residual RMS** | < 0.2 indicates accurate fit | ✅ 0.115 |

---

## 📘 Conclusion

Each program in the workflow plays a distinct role:

- **`torque_raise.py`**: torque calibration validation  
- **`torque_sinewave.py`**: single-frequency visual test  
- **`frequency_sweep.py`**: automated multi-frequency data collection  
- **`fit_model_from_sweep.py`**: model fitting and parameter extraction  

Together, these tools form a closed experimental–modeling loop that verifies the pendulum’s real-world dynamics and accurately extracts physical parameters **J**, **b**, and **k** for use in control design.

See also:
[This document](Pendulum_Modeling_Workflow.docx) which contains some formula

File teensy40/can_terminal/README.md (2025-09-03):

## Teensy CAN Test Programs

**Teensy sketches** that can be loaded to send commands over CAN to the MESC-based ESC. Each one uses a different control channel built into the firmware.  

---

### 1. `can_id_adc1_2_req.cpp`
- Use **`can_id_adc1_2_req.cpp`** for simple normalized throttle testing.  
- **CAN ID:** `CAN_ID_ADC1_2_REQ (0x010)`  
- **Payload:**  
  - Bytes 0–3 = `throttle_mapped` (float, normalized between **-1.0 and +1.0**)  
  - Bytes 4–7 = unused (`0.0f`)  
- **ESC Behavior:**  
  - Treated like a remote throttle input.  
  - Internally assigned to `motor_curr->input_vars.remote_ADC1_req`.  
  - Negative values = reverse torque, positive = forward torque.  
- **How to use:**  
  - Open Serial Monitor at 115200 baud.  
  - Type a float between `-1.0` and `+1.0`.  
  - Teensy sends that throttle value over CAN once.  
  - The ESC will respond if its **`remote_ADC_can_id`** matches the Teensy’s node ID (set via terminal: `set can_adc <id>`).  

---

### 2. `can_id_iqreq.cpp`
- Use **`can_id_iqreq.cpp`** for direct current/torque control.  
- **CAN ID:** `CAN_ID_IQREQ (0x001)`  
- **Payload:**  
  - Bytes 0–3 = `Iq_req` (float, in **amperes of q-axis current**)  
  - Bytes 4–7 = unused (`0.0f`)  
- **ESC Behavior:**  
  - Written directly into `motor_curr->FOC.Idq_req.q`.  
  - This is raw torque control, bypassing throttle mapping.  
- **How to use:**  
  - Open Serial Monitor at 115200 baud.  
  - Type a float (e.g. `5.0` or `-3.0`).  
  - Teensy will continuously stream that torque request at 500 Hz.  
  - The ESC will respond if its **`remote_Iq_can_id`** matches the Teensy’s node ID (set via terminal: `set can_iq <id>`).  

---

### Debugging in STM32CubeIDE
If you want to trace the command as it flows through the ESC firmware, good debug breakpoints are:  

- **`CAN1_RX0_IRQHandler()`** → Confirms the packet arrived in the ISR and was queued.  
- **`TASK_CAN_packet_cb()`** → Confirms the packet was dispatched to the right handler (ADC1_2_REQ or IQREQ).  
- **`MESCinput_Collect()`** → Confirms the chosen input value (CAN vs UART vs ADC) is being forwarded into the motor control loop.

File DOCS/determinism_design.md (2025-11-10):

# Determinism in the Brain Board Firmware

This document summarizes the design choices that keep the **balancing control loop deterministic** on the Teensy 4.0 brain board. The goal is to ensure that the 500–1000 Hz control-plane runs with minimal jitter (<50–100 µs) and is not disrupted by background I/O or logging.

---

## 1. Control Loop Triggering

- **Hardware timer (IntervalTimer)**
  - The control loop is triggered by a dedicated hardware timer (`g_ctrlTimer`).
  - The ISR does **not** perform heavy math; it only sets a flag (`g_control_due`).
  - The actual control computation runs in `loop()` when the flag is set.

**Impact:**  
Short ISR + hardware timer → consistent tick timing with minimal jitter.

---

## 2. Priority Ordering in `loop()`

The `loop()` function is structured in strict priority order:

1. **High priority:** if `g_control_due`, run `controlLoop()` immediately.  
2. **Medium priority:** poll CAN bus, enqueue RX frames, parse with `handleCANMessage()`.  
3. **Low priority:** update LEDs, speaker, pushbutton state, telemetry.  

**Impact:**  
Control always executes first. Lower-priority tasks never starve or delay the control path.

---

## 3. CAN Message Handling

- **Polling into a ring buffer**:  
  ```cpp
  while (Can1.read(msg)) {
      canBufferPush(canRxBuf, msg);
  }
  while (canBufferPop(canRxBuf, msg)) {
      handleCANMessage(msg);
  }
  ```
- The RX ISR is lightweight; heavy parsing is deferred to the main loop.
- CAN messages update ESC state variables (`pos_rad`, `vel_rad_s`, temps, etc.) with minimal memcpy operations.

**Impact:**  
No blocking or heavy logic inside ISRs → avoids introducing jitter.

---

## 4. Telemetry (Serial1 → ESP32)

- **TelemetryPacket (~56 B)** is prepared each cycle with `loadTelemetryPacket()`.
- Direct calls to `sendTelemetryPacket()` are **throttled** to a lower frequency (20–50 Hz), not sent every control tick.
- UART is initialized with a high baud rate (≥500 kbaud) to ensure packets drain fast.
- Optionally, use `availableForWrite()` to drop packets instead of blocking when buffer is full.

**Impact:**  
Telemetry runs at background rate, never blocks the 1 kHz control loop.

---

## 5. Non-blocking Background Tasks

- **LEDs** and **speaker** are updated with non-blocking state machines (`led_update()`, `tone_update()`).
- **Pushbutton** is debounced in software with microsecond timers, not delay loops.
- No `delay()`, `delayMicroseconds()`, or blocking waits inside `loop()`.

**Impact:**  
Background chores consume negligible time, ensuring deterministic control scheduling.

---

## 6. Avoiding Blocking I/O

- **No `Serial.printf` or `Serial.println` in the control loop.**
- Debug logging (e.g., CAN packet dumps) is only used during development and not in the real-time path.
- Telemetry and logging are designed as **background tasks**, not part of the critical loop.

**Impact:**  
Eliminates the risk of serial back-pressure introducing jitter.

---

## 7. Shared State and ESC Data

- ESC state variables(e.g., `pos_rad`, `vel_rad_s`, `MOS_temp`) are updated in `handleCANMessage()`.
- Reads happen in the control loop.  
- Although not double-buffered yet, updates are small single-word memcpy operations, reducing race condition risk.
- Double-buffering can be added later if needed for multi-variable consistency.

**Impact:**  
Lightweight state updates keep CAN parsing deterministic without blocking.

---

## 8. Measurement and Validation

- Jitter testing performed with scope toggling and DWT cycle counter confirms stable timing at ~20 kHz FOC loop and 500–1000 Hz control loop.
- CAN bus load (~25–50%) did not measurably affect loop timing.
- Telemetry is intentionally designed not to run at control frequency.

**Impact:**  
Empirical validation backs up the architectural choices.

---

## Key Principles Followed

- **ISR does the minimum necessary** (set a flag, push a byte).  
- **Control loop runs first** in priority order.  
- **Background I/O is decoupled** and throttled.  
- **No blocking calls in the control path.**  
- **Telemetry and logging are lossy by design** (okay to drop, never to block).  

---

### Conclusion

By structuring the firmware around these principles preserves a highly deterministic control path for the balancing robot. The control-plane runs at 500–1000 Hz with minimal jitter, while background tasks like CAN parsing, LED/speaker updates, and telemetry operate asynchronously without interfering with determinism. Measurement and testing will ensure that minimal jitter enters into the system. 

---

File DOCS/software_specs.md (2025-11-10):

# MESC Brain Board Documentation

### Overview
Most of this is nonesense. This document helped with thinking through firmware overview, and create really useful prompts for chatGPT.

#
### Hardware Interfaces / Peripherals
- Status indicators
  - Speaker
  - LEDs
    - Red
    - Green
- MPU6050 IMU
  - Interface: I2C
  - Tracks orientation and angular velocity
- PWM Inputs (from RC transceiver)
  - Used for manual control input
- CAN Bus (2 ports)
  - Connects to dual motor controllers (left and right)
  - Receives motor encoder, torque, velocity, and state information
  - Sends control commands (e.g. torque or velocity setpoints)
- UART to ESP32
  - ESP32 handles WiFi communications and remote telemetry
- UART to USB
  - term connection to computer

### Threads
- CAN
- Terminal
- User input
- Telemetry
- Speaker
- LEDs
- IMU

### Priority loop
- Calculating desired corrective torque/velocity
  - Process user input
  - Translating target to motor commands
- State management

### Control State Management
- CONTROL_IDLE
- CONTROL_ARMED
- CONTROL_MANUAL_RESET
- CONTROL_BALANCING
- CONTROL_TIPPED
- CONTROL_SHUTTING_DOWN

### Data structure for brain board
- Config
  - network name
  - node list
  - tipping_angle
  - max_turn
  - max_speed
  - ESC_num
- Raw input
  - PWM CH1-CH6
  - IMU I2C
  - User strings
  - UDP strings
- User_req
  - tilt_offset
  - speed
  - direction
  - left
  - right
  - P_input
  - I_input
  - D_input
- Params
  - obs_angle
  - obs_speed
  - tilt_offset
  - state
  - speed
  - direction
  - left
  - right
  - P_input
  - I_input
  - D_input
- Status
  - error
  - angle_initiated
- Error codes
  - TERM_FAILURE
  - TELEMETRY_FAILURE
  - IMU_FAILURE
  - RC_PWM_FAILURE
  - ANGLE_INIT_FAILURE
- LED1 control state
  - LED1_ON
  - LED1_FAST_BLINK
  - LED1_SLOW_BLINK
  - LED1_OFF
- LED2 control state
  - LED2_ON
  - LED2_FAST_BLINK
  - LED2_SLOW_BLINK
  - LED2_OFF
- Speaker control state
  - SPK_WARN1
  - SPK_WARN2
  - SPK_TRACK_BALANCE

### Data structure for each ESC
- Config
  - name 
  - node_id
  - pole_pairs
  - encoder_offset
  - max_amps
  - max_volts
  - min_volts
  - direction

- Raw input from controller, fast loop
  - adc1_2_req
  - speed
  - bus_volt
  - bus_current
  - motor_current
  - motor_voltage
  - FOC_angle

- Raw input from controller, slow loop
  - tmos
  - tmot
  - wanted: error_code

- Output to controller, fast loop
   - AMPS
   - DIRECTION

- Status
  - error

- Error codes
  - ESC_ERROR
  - ESC_OVERHEAT
  - ESC_OVERCURRENT
  - ESC_CAN
  - ESC_RESPONSE

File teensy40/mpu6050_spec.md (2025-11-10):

# MPU6050 Integration Specification for Two-Wheeled Balancing Robot (TWR)

This specification defines the complete, validated approach for using the MPU6050 IMU on a Teensy 4.0 to provide clean, low-noise roll and roll-rate estimates at 1 kHz for a balancing robot.

---

# 1. Electrical Integration

## 1.1 Required Connections

| MPU6050 Pin | Teensy 4.0 Pin | Notes |
|---|---|---|
| VCC | 3V3 | Do **not** use 5V. |
| GND | GND | Common ground required. |
| SDA | SDA (pin 18) | I²C0 on Teensy. |
| SCL | SCL (pin 19) | I²C0 on Teensy. |
| INT | pin 14 | Any digital pin with interrupts is acceptable. |

## 1.2 IMU Mounting
- Mount IMU **rigidly to the robot body** (not the motor frame).
- Use **gel/foam isolation** only for high-frequency vibration, not for structural motion.
- Z-axis aligned up/down; roll measured around X-axis.

---

# 2. I2C Configuration

## 2.1 Teensy
```cpp
Wire.begin();
Wire.setClock(400000);   // 400 kHz
```

## 2.2 MPU6050 Registers

### Digital Low-Pass Filter (DLPF)
Use bandwidth ~20–21 Hz:
```
CONFIG (0x1A) = 4
```
This removes motor vibration without excessive lag.

### Full-scale ranges
```
GYRO_CONFIG  = 0x10   // ±1000 dps
ACCEL_CONFIG = 0x08   // ±4 g
```

### Sampling
```
SMPLRT_DIV = 0
```
→ sensor outputs at **1 kHz** when DLPF enabled.

### FIFO
Enable accel + gyro:
```
USER_CTRL = 0x40
FIFO_EN   = 0x78
```

---

# 3. INT Pin Usage (Critical)

Using the INT output gives:
- One clean, jitter-free event per new sample (1 kHz).
- Eliminates stale-IMU-read problems.
- Allows you to fetch exactly one fresh sample per control loop.

### Configure INT pin:
```
INT_PIN_CFG (0x37) = 0b00110000   // LATCH_INT_EN + INT_RD_CLEAR
INT_ENABLE  (0x38) = 0b00000001   // DATA_RDY_EN
```

### Teensy ISR
```cpp
volatile bool imu_data_ready = false;

void imu_int_isr() {
    imu_data_ready = true;
}

pinMode(14, INPUT);
attachInterrupt(digitalPinToInterrupt(14), imu_int_isr, RISING);
```

### Clearing the interrupt
After reading FIFO, call:
```cpp
uint8_t status = imu.readReg(0x3A);  // INT_STATUS
```

---

# 4. FIFO Consumption Strategy

For each interrupt event:

1. Read FIFO count.
2. Drain **all but the last frame**.
3. Decode the final accel+gyro frame.
4. Use **only the newest frame** for the Mahony filter.

This ensures:
- No sample backlog
- Every IMU update corresponds to a fresh 1 ms sample

---

# 5. Filtering Requirements

## 5.1 Gyro Bias Estimation (Slow)
Track gyro bias only when vibration is low:

```cpp
if (fabs(gy_dps) < 5 && acc_mag between 0.9 and 1.1 g)
    bias_y += α_bias * (gy - bias_y);
```

Use **α_bias ≈ 0.001** (20-second time constant).

## 5.2 Gyro Low-Pass Filtering (Fast)
For roll-rate used in control:

Corner freq: **20 Hz**
```
roll_rate_filt += α_lpf * (gyro_corr - roll_rate_filt)
```

α_lpf for 1 kHz sampling:
```
α_lpf = 1 - exp(-2π * 20 / 1000) ≈ 0.11
```

## 5.3 Complementary / Mahony Filter
Use modified Mahony with **accelerometer trust factor**:

```
trust = 1 / (1 + 20 * |acc_mag - 1.0|)
```

- trust ≈ 1 → low vibration
- trust ≪ 1 → motor noise, accelerometer unreliable

Apply trust to both:
- proportional correction
- integral drift correction

---

# 6. IMU Outputs for the Balancing Controller

All angles/rates must be given in **radians** and **rad/s**.

- **roll_rad** = imu.roll * DEG_TO_RAD
- **roll_rate_rad_s** = imu.roll_rate * DEG_TO_RAD

Write to supervisor:

```cpp
sup->imu.roll        = roll_rad;
sup->imu.roll_rate   = roll_rate_rad_s;
sup->imu.pitch       = pitch_rad;       // not used in TWR
sup->imu.yaw         = 0;
sup->imu.valid       = true;
```

---

# 7. Control Loop Timing

- Teensy control loop runs at **1 kHz** via IntervalTimer ISR.
- Each tick:
  - Check `imu_data_ready`
  - If true:
    - Clear flag
    - Call `imu.update()`

### DO NOT run imu.update() unconditionally.  
This causes:
- stale samples
- random lag
- huge RMS roll-rate

---

# 8. Telemetry & Debug

Send only:
```json
{"t": ..., "roll": <rad>, "roll_rate": <rad/s>}
```

Plot in Python:
- Roll (deg or rad)
- Roll rate
- RMS (normalized over ~200 samples)
- Motor on/off tests

Normal RMS(roll_rate):
- Motors off: < 0.5–1.5 deg/s
- Motors on: 2–5 deg/s
- When falling: spikes are normal

If RMS stays >20 deg/s → IMU update rate mismatch or stale samples.

---

# 9. Failure Modes & Diagnostics

| Symptom | Cause |
|---|---|
| Roll stays constant | imu.update() not getting fresh FIFO data (INT missing) |
| Roll jumps wildly | accel trust too high; vibration corrupts gravity vector |
| Roll_rate huge noise | gyro bias not compensated or LPF not applied |
| IMU update slow | FIFO not drained, or I2C errors |
| Balancer oscillates | wrong units (deg vs rad), unfiltered state, or bad signs |

---

# 10. Summary: What You Must Implement

✅ **INT pin wired & ISR to flag new samples**  
✅ **Interrupt-driven FIFO read** (not timer-based guessing)  
✅ **Gyro bias tracking**  
✅ **Gyro low-pass filtering (20 Hz)**  
✅ **Mahony with variable accelerometer trust**  
✅ **Export roll & roll_rate in radians**  
✅ **Use filtered roll_rate for LQR**  
✅ **Plot & verify RMS stability**  

Once all above is implemented, the IMU subsystem is *sufficient for stable balancing*.

---

# Appendices
- Appendix A: Register reference for INT and DLPF
- Appendix B: Gyro/accel scaling constants
- Appendix C: Recommended test procedures

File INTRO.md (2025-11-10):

# MESC BRAIN BOARD PROMPT

This is a PCB and software development project for a balancing robot. 

The goal is to use a hobby Electronic Speed Controller (one open source [example](https://github.com/owhite/MP2-DFN), and this circuit for a [brain board](https://github.com/owhite/MESC_brain_board/blob/main/brainboardV1.0/MESC_brain_board.pdf), a teensy 4.0, and an ESP-32, in combination with [MESC firmware](https://github.com/davidmolony/MESC_Firmware).

## GENERAL APPROACH

A separation of concerns is divided across these architectures:

* **Teensy:** Runs the high-level brain → gait generator, balance estimator, RC inputs
* **MESC:** The firmware on the ESC for control → torque or velocity loops per joint
* **ESP32:** Easy to log and analyze later → pumps UDP to the computer
* **Desktop computer** → perfectly adequate way of viewing high speed data with UDP

## TEENSY 4.0
* 600+ MHz ARM Cortex-M7 — plenty of headroom for filtering, control loops, gait logic, telemetry
* Tons of I/O for IMU, encoders, RC input, WiFi (via ESP add-on), etc.
* Precise timing with elapsedMicros or interrupts for deterministic control
* Great for real-time control, sensor fusion, and behavior modeling

## MESC MOTOR CONTROLLER
* Executes low-level Field-Oriented Control (FOC) motor control 
* DIY and commercially available boards
* Built-in support for encoders, FOC, and torque estimation
* Accurate low-level motor control using current sensing
* Reads angular position from the MT6701 encoder via SPI or PWM
* UART/CAN interface (RX + TX)	Real-time communication with the Teensy
* PWM / FOC commutation w/ efficient, smooth motor operation

## OTHER BRAIN BOARD FEATURES
* RC receiver connector (for PWM/PPM/SBUS input)
* ESP32 UART serial programmer
* Power input connector
* Voltage divider (to monitor battery voltage)
* Push-button E-stop connector
* IMU connector (e.g., MPU-6050)
* Buzzer (for system alerts or E-stop signal)
* CAN connector (for MESC motor control)
* The ESC connects to a MT6701 encoder

## CAN BUS
* Full-duplex communication between Teensy and motor controllers
* Carries:
  * Commands: set_torque, set_velocity, enable_motor, zero_encoder, etc.
  * Telemetry: encoder position, estimated torque, velocity, fault codes
* Real-time performance with minimal latency
* Can support multiple motor controllers on the same bus

## Teensy Firmware
- main() 
   - supervisor is initialized which handles much of the control loop activities
   - has an ISR that will enter into the control loop at 1000 Hz
   - note this line: `controlLoop(imu, &supervisor, Can1);`
- controlLoop is in superverer.cpp 
- given the correct state, controlLoop enters `run_mode_balance_TWR(sup, can);` which handles balancing activities

A subset of main() is here: 

```
#include <FlexCAN_T4.h>
#include "LED.h"
#include <ArduinoJson.h>
#include "main.h"
#include "pushbutton.h"
#include "tone_player.h"
#include "MPU6050.h"
#include "ESC.h"
#include "CAN_helper.h"
#include "supervisor.h"

// ---------------------- Setup / Loop -----------------------
IntervalTimer g_ctrlTimer;
MPU6050 imu;
Supervisor_typedef supervisor;

const char* esc_names[]   = {"left", "right"};
const uint16_t esc_ids[]  = {11, 12}; // node_ids of the ESCs
const uint8_t rc_pins[]   = {RC_INPUT1, RC_INPUT2, RC_INPUT3, RC_INPUT4};

// -------------------- CAN Communication --------------------
FlexCAN_T4<CAN1, RX_SIZE_256, TX_SIZE_16> Can1;
CANBuffer canRxBuf;  // ✅ holds buffer + link_ok

// -------------------- Tone / Pushbutton --------------------
static TonePlayer g_tone;
PushButton g_button(PUSHBUTTON_PIN, true, 50000u);

// --------------------- LED instances -----------------------
static LEDCtrl g_led_red;
LEDCtrl g_led_green;

void setup() {
  Wire.begin();
  Wire.setClock(400000);
  imu.begin();

  init_supervisor(&supervisor,
                  2,           // esc_count -- FIX: dont hard code this number
                  esc_names,   // ESC names
                  esc_ids,     // ESC node IDs
                  rc_pins,     // RC pins
                  4);          // RC count -- FIX: dont hard code this number

  // LEDs / Pushbutton / Tone
  led_init(&g_led_red,   LED1_PIN, LED_BLINK_SLOW);
  led_init(&g_led_green, LED2_PIN, LED_BLINK_FAST);
  tone_init(&g_tone, SPEAKER_PIN);

  // ---- Control tick ISR ----
  g_ctrlTimer.priority(CONTROL_LOOP_PRIORITY);
  g_ctrlTimer.begin(controlLoop_isr, CONTROL_PERIOD_US);

  // ---- CAN Setup ----
  Can1.begin();
  Can1.setBaudRate(500000);
  Can1.enableFIFO();
}

void loop() {
  // -------- HIGH PRIORITY --------
  // Set to CONTROL_PERIOD_US = 1000 µs (1000 Hz).
  //   note that is faster than rate of CAN coming from MESC
  // The system uses an ISR-driven scheduler to tell the main loop to go into controlLoop. 
  // ---
  if (g_control_due) {
    controlLoop(imu, &supervisor, Can1);
    g_control_due = false;
  }

  // -------- CAN POLLING --------
  // Non-blocking and not based on an ISR because FLEXCAN_T4 did seem to work. 
  // ---
  CAN_message_t msg;
  while (Can1.read(msg)) {
    canBufferPush(canRxBuf, msg);
  }
  while (canBufferPop(canRxBuf, msg)) {
    handleCANMessage(msg);
  }

  static String input = "";

  // -------- LOW PRIORITY --------
  // These functions are intentionally throttled using a x10 time divider
  // ---
  static uint32_t last_lowprio_us = 0;
  uint32_t now_us = micros();

  if (now_us - last_lowprio_us >= (CONTROL_PERIOD_US * 100)) {
    last_lowprio_us = now_us;

    while (Serial.available()) {
      char c = Serial.read();
      if (c == '\n') {
	// Try to parse the accumulated line
	JsonDocument doc;
	DeserializationError err = deserializeJson(doc, input);
	if (!err) {
	  // Receives a string like: 
	  // {'cmd': 'run_balance', 'pulse_torque': 0.2, 'pulse_us': 250000, 'total_us': 3000000, 'user_Kp_term': 6.26, 'user_Kd_term': 0.6}

	  if (doc.containsKey("cmd") && doc["cmd"] == "run_balance") {
	    /* 
	    if (doc.containsKey("pulse_torque"))
	      supervisor.user_pulse_torque = doc["pulse_torque"];
	      etc...
	    */ 

	    tone_start(&g_tone, PB_BEEP_HZ, PB_BEEP_MS, PB_GAP_MS);
	    if (supervisor.mode == SUP_MODE_BALANCE_TWR) {
	      supervisor.mode = SUP_MODE_IDLE;
	    }
	    else {
	      supervisor.mode = SUP_MODE_BALANCE_TWR;
	    }
	  }
	}
	input = "";
      } else {
	input += c;
      }
    }

    // 1 Hz HEALTH CHECK
    if (millis() - supervisor.last_health_ms > 1000) {
      supervisor.last_health_ms = millis();
      led_set_state(&g_led_green, canRxBuf.link_ok ? LED_ON_CONTINUOUS : LED_BLINK_SLOW);
    }

    // Handling of pushbutton, LED stuff. 

    // Resets timing stats
    if (supervisor.timing.count > 0) { resetLoopTimingStats(&supervisor);  }
  } // end of low priority loop
}
```

a subset of controlLoop() is here:

```
void controlLoop(MPU6050 &imu,
                 Supervisor_typedef *sup,
                 FlexCAN_T4<CAN1, RX_SIZE_256, TX_SIZE_16> &can)
{
    uint32_t start_us = micros();

    // --------- Loop Jitter Measurement ---------
    static uint32_t last_us = 0;
    if (last_us == 0) last_us = start_us;

    uint32_t dt_us = start_us - last_us;
    last_us = start_us;

    sup->timing.dt_us = dt_us;
    sup->timing.sum_dt_us += dt_us;
    sup->timing.count++;

    if (dt_us < sup->timing.min_dt_us) sup->timing.min_dt_us = dt_us;
    if (dt_us > sup->timing.max_dt_us) sup->timing.max_dt_us = dt_us;
    if (dt_us > CONTROL_PERIOD_US + 100) sup->timing.overruns++;

    // ============================================================
    //                        IMU UPDATE
    // ============================================================
    imu.update();   // IMU now produces roll_rad + roll_rate_rad_s

    uint32_t now_us = micros();

    // Convert IMU outputs to radians
    // (IMU roll and pitch are exported in DEGREES)
    const float roll_rad  = imu.roll * DEG_TO_RAD;
    const float pitch_rad = imu.pitch * DEG_TO_RAD;

    // roll_rate is exported in DEGREES/second → convert to rad/s
    const float roll_rate_rad_s = imu.roll_rate * DEG_TO_RAD;

    // --- Store into supervisor IMU struct ---
    sup->imu.roll        = roll_rad;
    sup->imu.pitch       = pitch_rad;
    sup->imu.yaw         = 0.0f;   // MPU6050 cannot provide yaw without magnetometer
    sup->imu.roll_rate   = roll_rate_rad_s;

    sup->imu.valid           = true;
    sup->imu.last_update_us  = now_us;
 
    // ============================================================
    //                        RC UPDATE
    // ============================================================
    updateRC(sup);

    // ============================================================
    //                 EXECUTE CURRENT SUPERVISOR MODE
    // ============================================================
    switch (sup->mode) {

    case SUP_MODE_IDLE:
    {
        // Send zero torque periodically
        if (++telem_counter >= TELEMETRY_DECIMATE) {
            telem_counter = 0;

            CAN_message_t msg1, msg2;

            msg1.id = canMakeExtId(CAN_ID_IQREQ, TEENSY_NODE_ID,
                                   sup->esc[0].config.node_id);
            msg2.id = canMakeExtId(CAN_ID_IQREQ, TEENSY_NODE_ID,
                                   sup->esc[1].config.node_id);

            msg1.len = msg2.len = 8;
            msg1.flags.extended = msg2.flags.extended = 1;

            canPackFloat(0.0f, msg1.buf);
            canPackFloat(0.0f, msg1.buf + 4);
            canPackFloat(0.0f, msg2.buf);
            canPackFloat(0.0f, msg2.buf + 4);

            can.write(msg1);
            can.write(msg2);
        }
        break;
    }

    case SUP_MODE_BALANCE_TWR:
        run_mode_balance_TWR(sup, can);
        break;

    default:
        break;
    }

    // --------- Track Execution Time ---------
    sup->timing.exec_time_us = micros() - start_us;
}
```

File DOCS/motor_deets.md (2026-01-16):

## GBM5208-200T
- set par_ld 0.0054
- set par_lq 0.009 
- set par_r 8.5 Ω per phase

## GIM4305-10 Steadywin
- set par_ld 0.00014
- set par_lq 0.00021
- set par_r .65 

## FLIPSKY 6215 KV170
- set par_ld 0.000015
- set par_lq 0.000022
- set par_pp 14      
- set par_r  0.070000

## GL80 KV30
- set par_ld 0.00057 
- set par_lq 0.00082
- set par_pp 21
- set par_r  1.13

## QS165 V2
- set par_ld 0.000042
- set par_lq 0.000065
- set par_pp 14 ?? 
- set par_r 0.006000

## Generic skateboard motor

36v 1600rpm skateboard motor, 
- No-load Current: 0.3A
- Maximum Current: 12A
- Speed: 15-20KM/h.
- KV ≈ 1600 / 36 ≈ 44.4 rpm/V
- set par_r 0.357
- set par_ld 0.000081
- set par_lq 0.000162

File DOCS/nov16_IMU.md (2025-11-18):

## Nov 16th, 2025

## Inertia Measurement Unit Testing

During bench testing of the Two-Wheeled Robot (TWR) control stack, the MPU6050 IMU exhibited significant vibration-induced noise when the motors were energized. The Teensy is executing the run_mode_balance_TWR() loop at 500 Hz, using IMU-derived roll and roll-rate feedback for the LQR controller.

When the motors are off, both signals are stable and near-DC, confirming correct sensor setup and minimal electrical noise. However, when the motors spin (with the robot frame fixed to a test board), the roll-rate signal shows ±1 deg/s jitter and small bias drift, indicating mechanical coupling of motor and chassis vibrations into the IMU.

```
$ ./IMU_test.py -p /dev/cu.usbmodem178888901
```

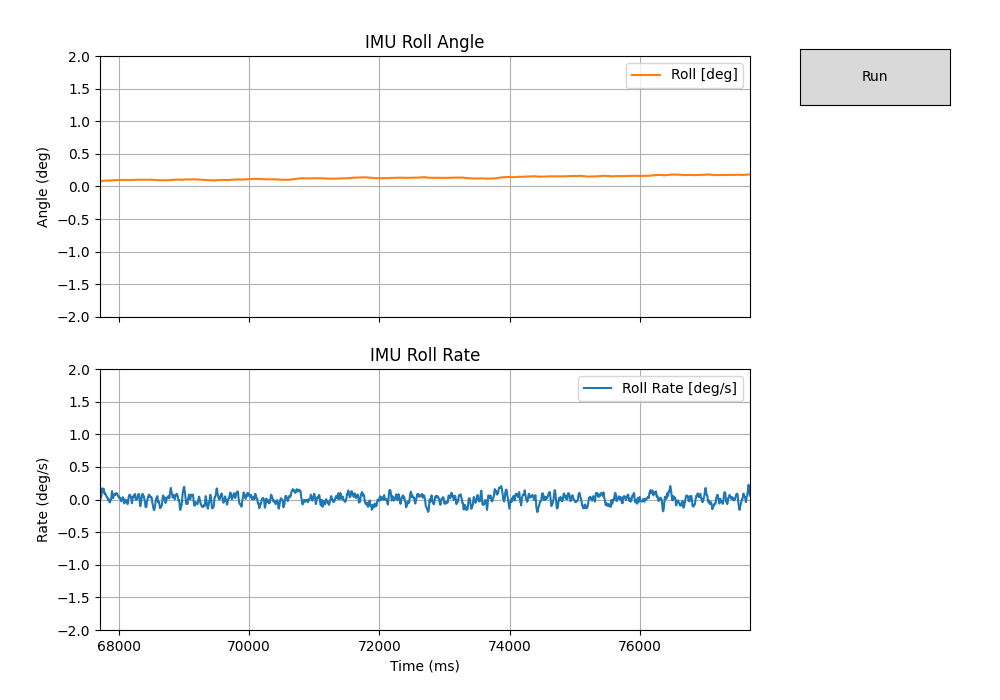
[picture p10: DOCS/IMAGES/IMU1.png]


and this is with:

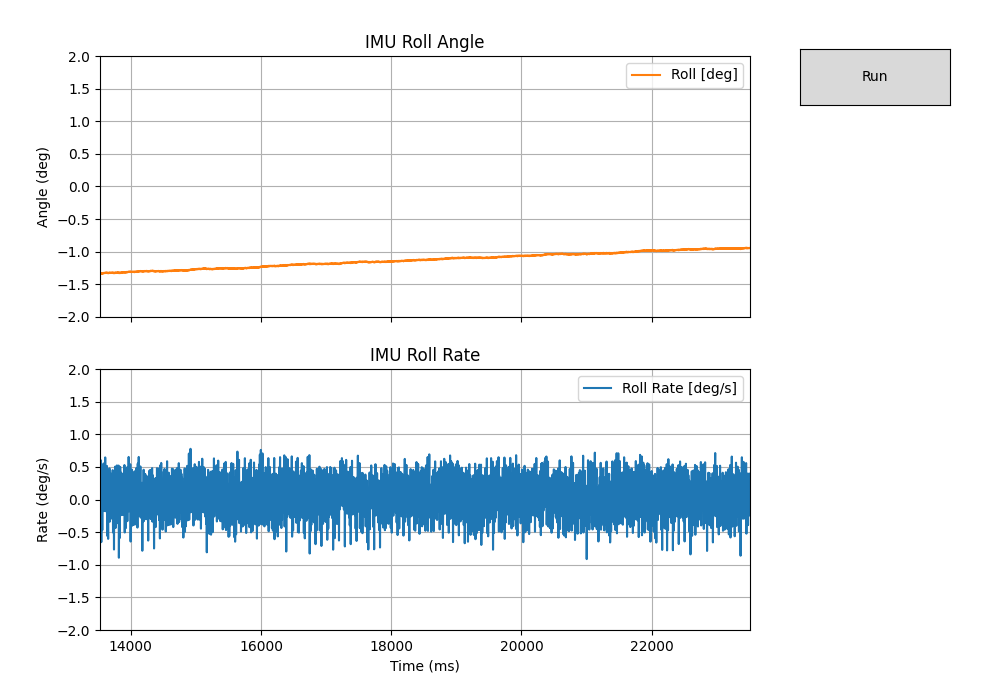
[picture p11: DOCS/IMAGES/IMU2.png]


## Roll-rate root mean square:

**RMS (Root Mean Square)** is a statistical measure of signal energy. For IMU roll-rate data, RMS quantifies the **average noise level** of the gyro signal over a short window of time (e.g., 200 samples ≈ 0.4 s at 500 Hz). It compresses a noisy signal into a single scalar that reflects how “quiet” or “vibratory” the measurement is.

Because self-balancing robots rely heavily on roll-rate (θ̇) feedback, excessive noise directly affects controller stability, causes jitter in torque output, and can lead to oscillations or instability. RMS is therefore a useful indicator of **sensor quality, mechanical isolation effectiveness, and motor-induced vibration.**

Ideal operation would be:
- Motors off (idle):
- 0.05–0.20 deg/s RMS
- means a clean gyro data and low mechanical noise.
- Motors on, wheels off ground:
   - 0.20–0.50 deg/s RMS
   - Typical for a well-isolated IMU.

Acceptable but monitor:
- 0.50–1.00 deg/s RMS
- Some vibration coupling.
- Controller may still behave, but there could be torque “buzzing.”

Let's look at some data. Turn off the motors, and one hard desk bang causes this:

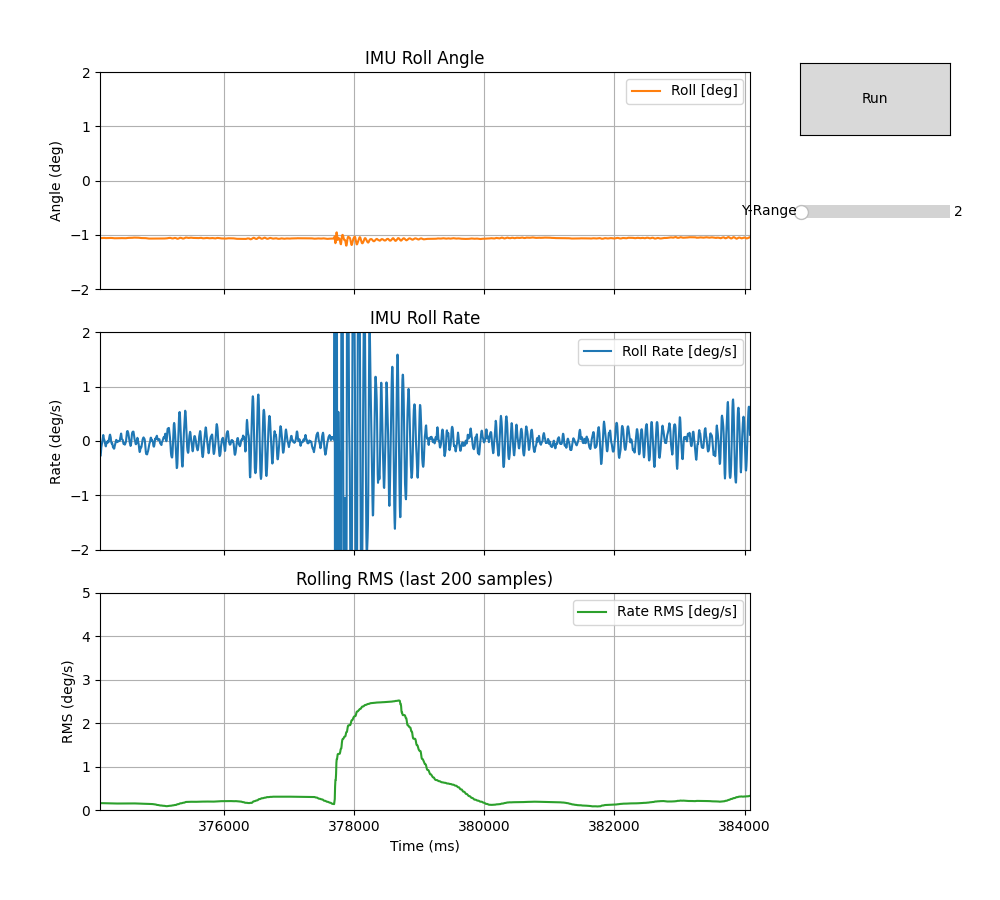
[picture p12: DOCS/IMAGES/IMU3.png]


**This is good news.** If the robot receives a mechanical impact, the IMU reports a temporary rise in roll-rate RMS, up to ~2–3 deg/s. This is expected and represents real physical disturbance, not measurement noise. The RMS rapidly returns to baseline (≈0.1–0.3 deg/s), indicating low steady-state noise, adequate mechanical damping, and no problematic chassis resonance.

- RMS ~0.1–0.3 deg/s at steady state → Very clean IMU data.
- A fast rise in RMS up to ~2.5 deg/s.
- A clean decay back to baseline over ~200–400 ms.
- No lingering resonance.
- No secondary ringing.

Let's try it with the motors running: 

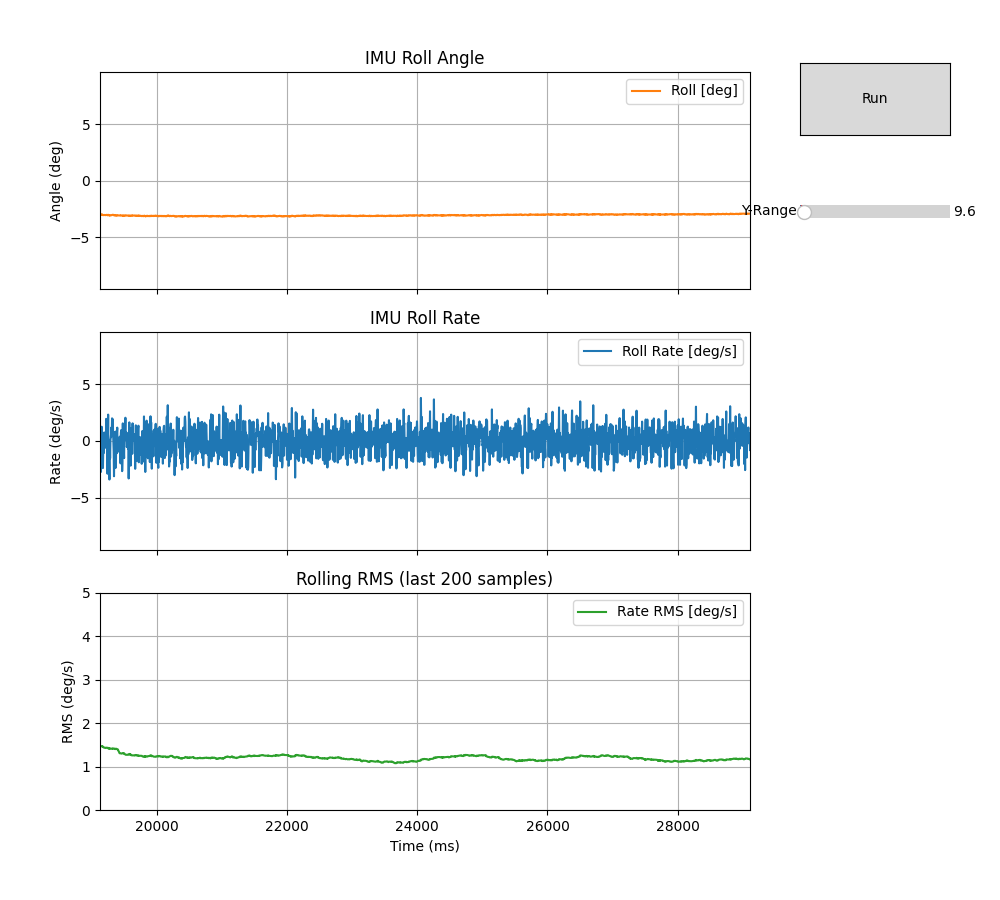
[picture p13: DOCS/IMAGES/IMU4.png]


**This is also good news.**

- This is typical for a wheel-in-the-air test.
- Roll angle has small DC drift of a few degrees (normal due to chassis flex + IMU bias).
- No jitter or high-frequency artifacts.
- IMU orientation estimate is stable.
- Roll rate (raw-ish gyro rate), noise amplitude is roughly ±2–4 deg/s
- Centered around 0
- Broad vibration band → this is expected motor vibration, not sensor instability
- No strong narrow-band resonance → great sign
- No drift → bias stable
- Peak RMS ~3.3 deg/s at motor spin-up
- Settles to ~1.2–1.5 deg/s steady state
- Clean exponential decay after spin-up
- This RMS level is acceptable for control.

**General rules of thumb:**

| Condition | RMS (deg/s) | Interpretation |
| --- | --- | --- |
| **Excellent / motors off** | 0.1–0.3 | Ideal |
| **Good / motors on** | 0.3–0.7 | Normal |
| **Acceptable** | 0.7–1.5 | Usable |
| **Concerning** | 1.5–2.0 | Needs checking |
| **Problematic** | >2.0 sustained | Likely resonance or poor mounting |

## Additional filtering

A chunk of time has gone by and the **MPU6050 is behaving really poorly when the bot is trying to balance**. (Sorry, I did not make a graph of this). When the controller is on there is no way to get RMS down to a reasonable level, and almost as worse **readings for the tilt position of the robot were terrible**. This led to me switching to using an ICM-42688, and applying Mahony filtering. 

A Mahony filter is a lightweight, quaternion-based sensor fusion algorithm used to estimate 3-D orientation from an IMU. It combines gyroscope and accelerometer measurements in a way that:

- uses the gyroscope for smooth, low-noise short-term rotation tracking
- uses the accelerometer as a long-term reference for the gravity direction
- automatically rejects accelerometer readings that don’t match gravity (e.g., vibration, linear acceleration)
- continuously estimates and removes gyro bias so the angle does not drift over time

the filter compares the gravity vector predicted by the current quaternion to the gravity vector measured by the accelerometer. The difference becomes an error signal, which is fed back into the gyroscope via proportional (Kp) and integral (Ki) terms. The corrected gyro is then integrated into the quaternion.

Here is an example of running the bot with the wheels off the ground, but still chattering away. The full 3-axis Mahony filter produced a clean, stable pitch estimate that no longer drifts when the motors run. The filter automatically rejects vibration-induced accelerometer noise and uses gyro bias correction to keep the angle accurate over time. As a result, the robot’s tilt measurement is now smooth, responsive, and reliable enough for precise balance control.

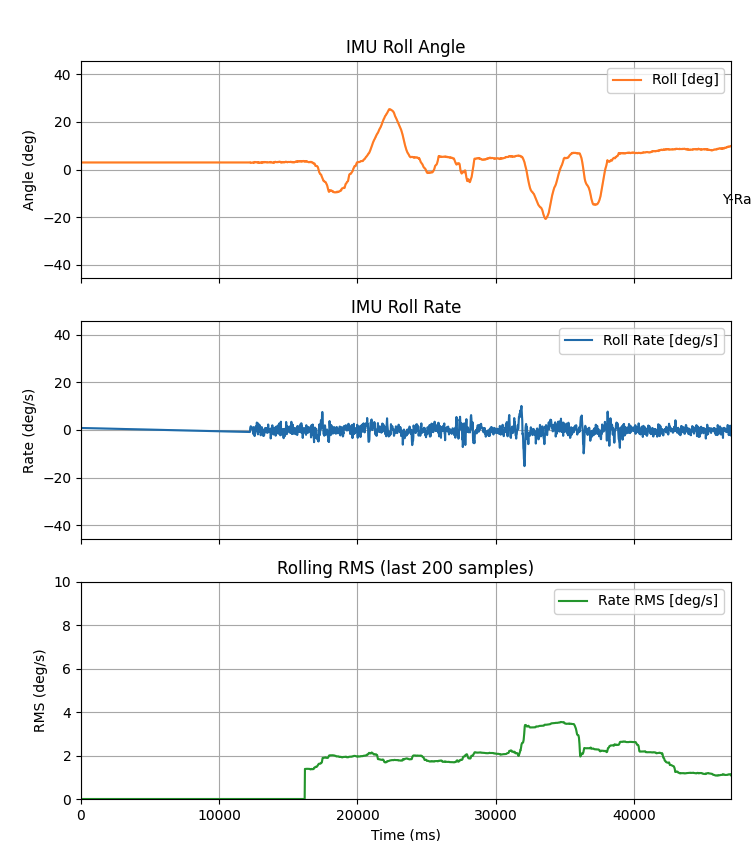
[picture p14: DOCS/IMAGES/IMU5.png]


## Deets

Most of the work done here should be reproducible with this commit:

hash id: `9633b44677406c790000eb56cd1858c216e7f7b5`

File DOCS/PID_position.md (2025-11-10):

# Examples of PID working and not working

The way the code is set up is if the user hits the button we switch to a supervisor mode that sets the position
```c

  if (pb_state == PB_PRESSED) {
	// SPEAKER
	tone_start(&g_tone, PB_BEEP_HZ, PB_BEEP_MS, PB_GAP_MS);
      }
      else if (pb_state == PB_RELEASED && g_button.isArmed()) {

	// User can switch mode by pressing button
	SupervisorMode test_mode = SUP_MODE_SET_POSITION;

	if (supervisor.mode == test_mode) {
	  supervisor.mode = SUP_MODE_IDLE;
	} else {
	  supervisor.mode = test_mode;
	}
   }
```

Using this code block, and many different settings for Kp and Kd, I got no where with trying to get motor to move to position under PID control. 

```c
void run_mode_set_position(Supervisor_typedef *sup,
                           FlexCAN_T4<CAN1, RX_SIZE_256, TX_SIZE_16> &can) {
    static bool first_entry = true;
    static unsigned long start_time = 0;

    const float Kp = 0.04f;
    const float Kd = 0.005f;
    const float setpoint = M_PI;   // target position

    if (first_entry) {
        logIndex = 0;
        first_entry = false;
        start_time = micros();
    }

    // --- PID control ---
    float pos_err = setpoint - sup->esc[0].state.pos_rad;
    if (pos_err >  M_PI) pos_err -= 2.0f * M_PI;
    if (pos_err < -M_PI) pos_err += 2.0f * M_PI;

    float vel_err = 0.0f - sup->esc[0].state.vel_rad_s;

    float p_term = Kp * pos_err;
    float d_term = Kd * vel_err;
    float cmd_torque_raw = p_term + d_term;

    // clamp torque
    const float TORQUE_CLAMP = 0.8f;
    float cmd_torque = constrain(cmd_torque_raw, -TORQUE_CLAMP, TORQUE_CLAMP);

    // --- Output command over CAN ---
    CAN_message_t msg;
    msg.id = canMakeExtId(CAN_ID_IQREQ, TEENSY_NODE_ID,
                          sup->esc[0].config.node_id);
    msg.len = 8;
    msg.flags.extended = 1;
    canPackFloat(cmd_torque, msg.buf);
    canPackFloat(0.0f, msg.buf + 4);
    can.write(msg);

    // --- Logging ---
    if (logIndex < 1000) {
        logBuffer[logIndex++] = {
            micros() - start_time,
            setpoint,
            sup->esc[0].state.pos_rad,
            sup->esc[0].state.vel_rad_s,
            pos_err,
            cmd_torque,
	    p_term,
	    d_term
        };
    } else {
        // Done collecting: print JSON burst
        Serial.println("{ \"samples\":[");
        for (int i = 0; i < 1000; i++) {
	  Serial.printf(
			"{\"t\":%lu,\"setpoint\":%.4f,\"pos\":%.4f,"
			"\"vel\":%.4f,\"err\":%.4f,"
			"\"torque\":%.4f,\"p_term\":%.4f,\"d_term\":%.4f}%s\r\n",
			logBuffer[i].t_us,
			logBuffer[i].setpoint,
			logBuffer[i].pos,
			logBuffer[i].vel,
			logBuffer[i].error,
			logBuffer[i].torque,
			logBuffer[i].p_term,
			logBuffer[i].d_term,
			(i < 999) ? "," : ""
			);

        }
        Serial.println("]}\r\n");

        // Reset and exit to idle
        sup->mode = SUP_MODE_IDLE;
        first_entry = true;
    }
}

```

## Resulting plots are here. This a sort of good example: 

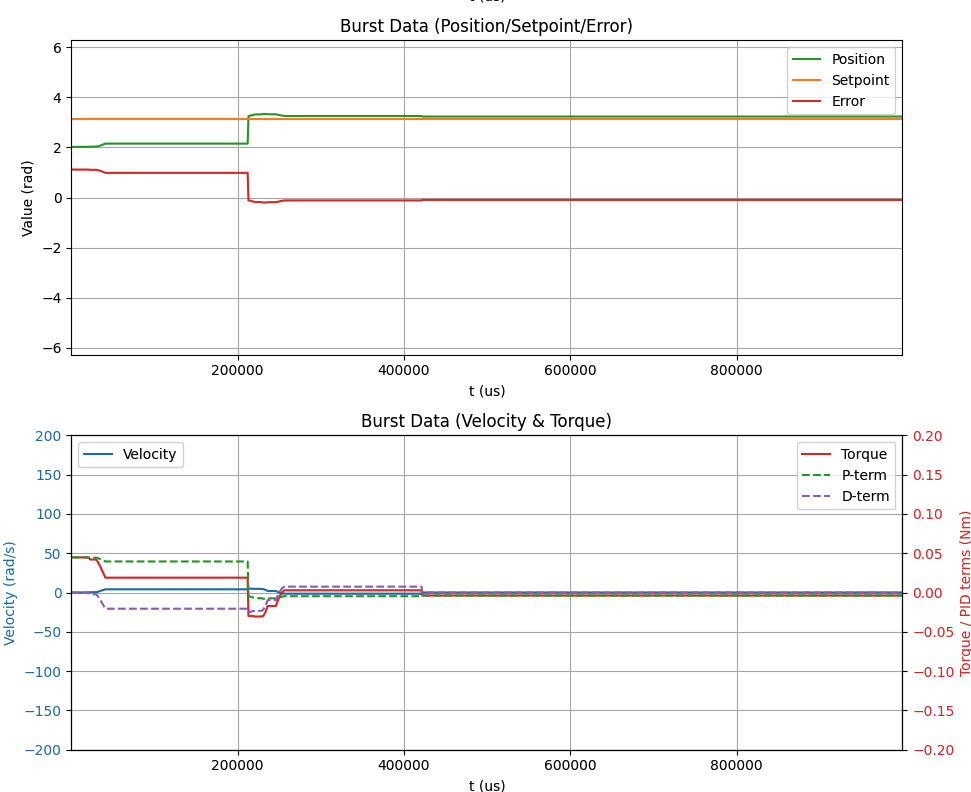
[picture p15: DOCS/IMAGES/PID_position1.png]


## And these are sucktastic:

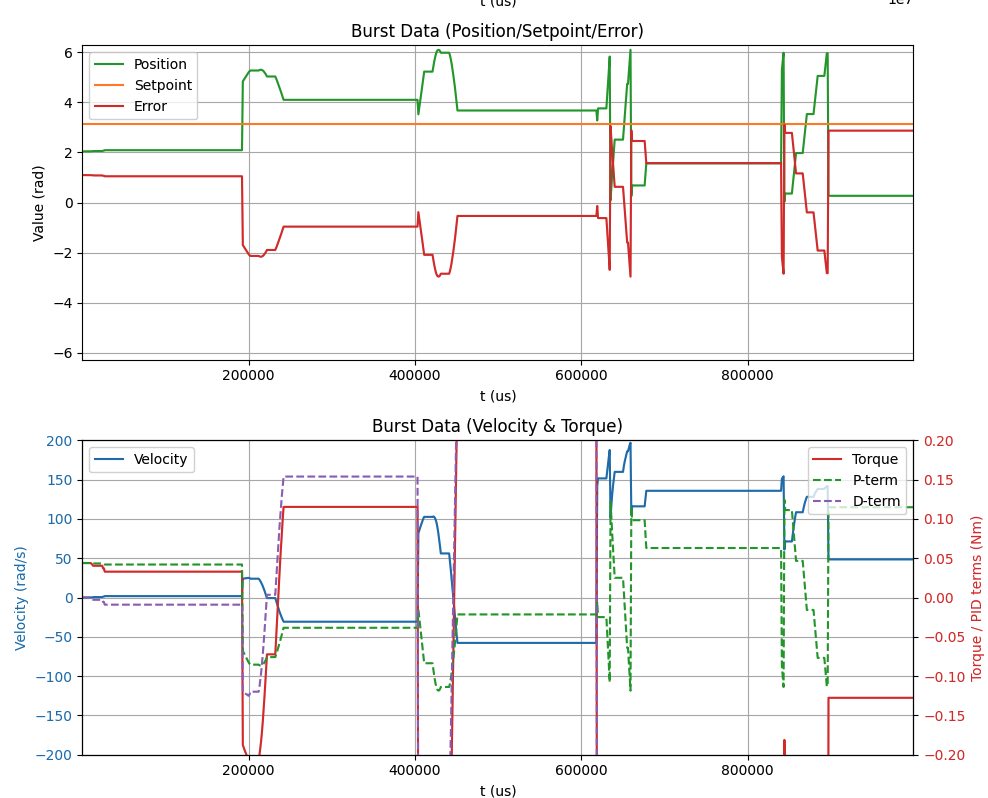
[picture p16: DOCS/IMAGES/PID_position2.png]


----

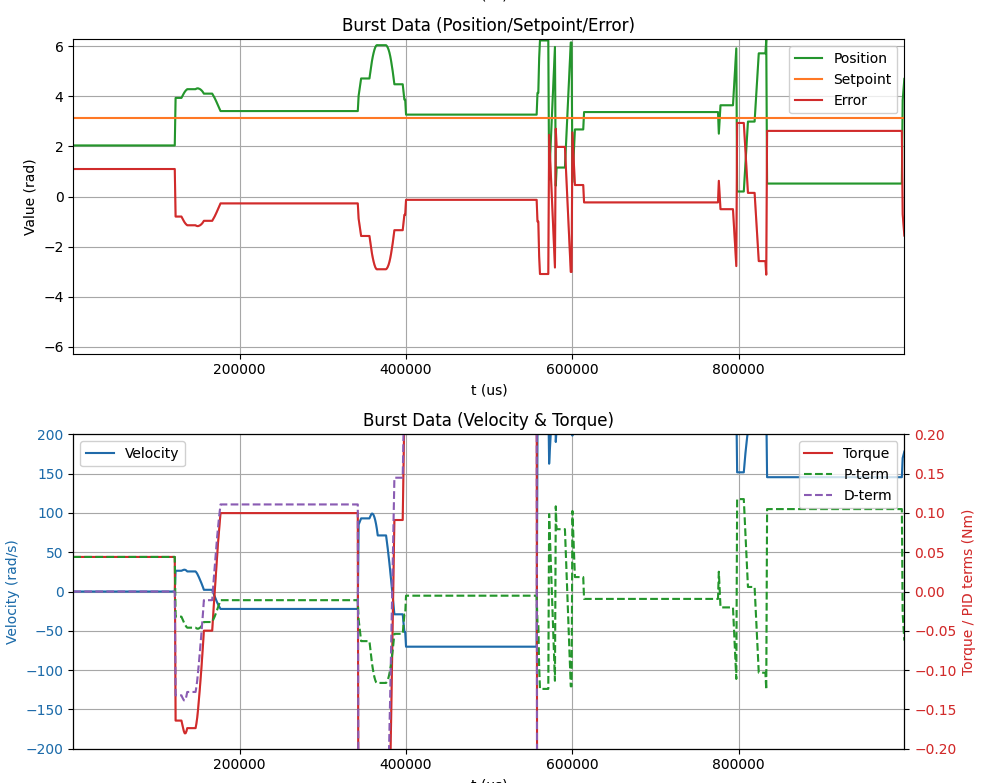
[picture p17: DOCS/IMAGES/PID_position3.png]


- very little reproducibility
- same settings produce different results
- major risk: going down rabbit holes you can consider all the issues [here](sept19_torque_nonlinearity.md)

## The good news is this, what I found was: 

- The teensy is running its control loop at 1 kHz but my configuratino of MESC sent data at 500 Hz.
- If you're not careful the teensy reused stale velocity samples
- The fix was to basically gate calculations, by adding this to the top of the control loop:

```c
if (!sup->esc[0].state.alive) return;
.
. rest of code
.
sup->esc[0].state.alive = false;

``` 
This only updates when fresh CAN message arrives.

This aligned Teensy’s control loop with ESC data → noise and D-term chaos disappeared.

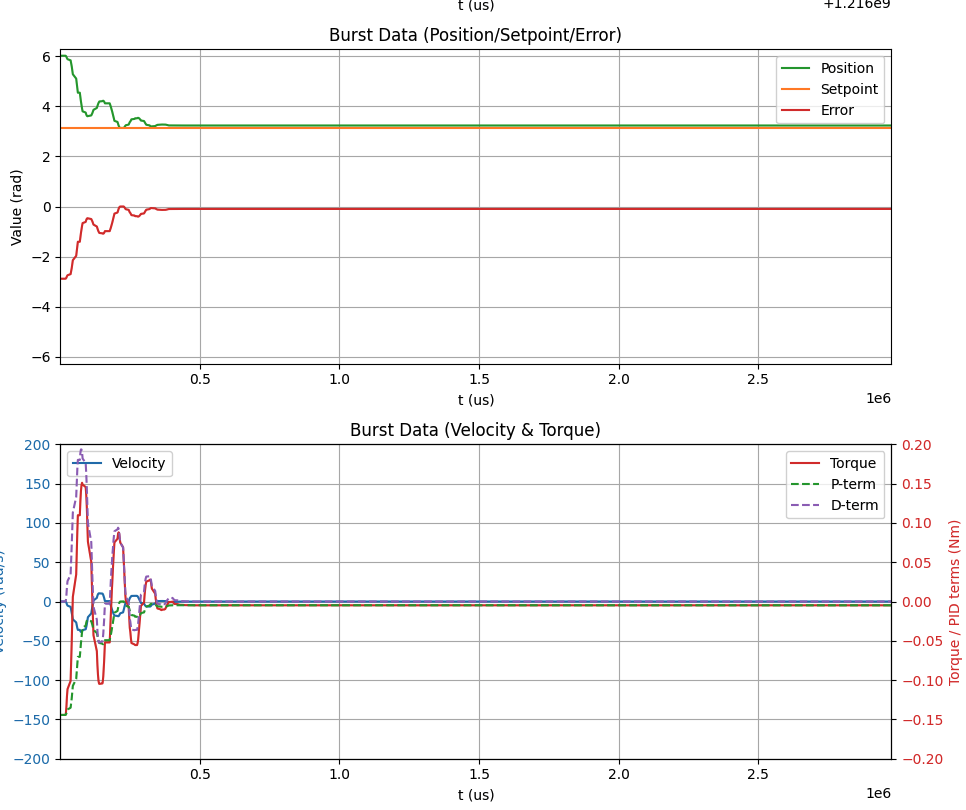
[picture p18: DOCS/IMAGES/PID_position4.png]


## Parameterizing

- Checkout this hash a5a77bc746598f7f1fc24ee28c335967a3400e68 to reproduce.
- Load on to teensy.
- Load code [link](https://github.com/owhite/MESC_brain_board/tree/main/teensy40/PID_position) on to teensy
- Then run on the command line:
  - $ python3 ./position_burst.py /dev/cu.usbmodem178888901
- Set motor position.
- Hit button on brain board, or hit run on python interface.
- Changing PD settings saves to disk and sends start command to control plant. 
- Current outcome is discussed [here](sept23_PID_notes.md)

## Unfortunately, these have been simple no-load motor tests. 

- When the motor is spun with no load, the controller looks unstable and oscillatory even with small gains.
- No inertia or resisting torque — the rotor accelerates instantly, overshoots. 
- The feedback loop chases its own tail.
- Integral action is meaningless here (no steady disturbance to fight).
- This has been useful to verify plumbing: 
  - CAN messaging, encoder direction, logging
  - Confirming that P, I, and D terms work in principle.
- It tells you almost nothing about how the system will behave when stabilizing a real unstable plant like a balancing robot.

## An inverted pendulum would be far better for testing

The fact is that a free-spinning motor under no load is just a wiring check. An inverted pendulum on the motor shaft is a true physics test of a controller.

Because:
- The critical state is body angle (θ) and its rate (θ̇).
- Encoders on free-spinning wheels don’t give body tilt; an IMU is normally used.
- The new plan: inverted pendulum test rig

Mechanical setup:
- Mount an arm rigidly on the motor shaft, with a weight at the end.
- Motor shaft horizontal, arm pointing up → defines the unstable equilibrium.
- Add stops or bumpers so the arm can’t swing 360°.

Sensor setup:
- Use the motor’s encoder to measure arm angle.
- Define “relative zero” at the upright top position.

Control setup:
- Start with PD control. 
- P-term provides restoring torque to pull arm upright.
- D-term damps oscillations.
- I-term only after P–D balance is stable, to cancel offsets (friction, misalignment).
- If this works, great, then move on to LQR

## Bottom line

- It took a while but even with pendulum testing I discovered **PID is a fun-house mirror of meaningless gains**
- A balancing robot is a double-integrator–plus–gravity system. 
   - The wheel torques accelerate the body
   - The body angle integrates the rate
   - Disturbances enter everywhere
   - The dynamics are state-based, not error-based
- **PID has no clue about any of this.**
- It looks like you’re controlling the robot, but you’re actually tuning a distorted reflection of the system.

I later learned that LQR at least gives you a fighting chance of understanding the system. Because instead of tuning gains blindfolded, 1) you model the system (linearized Euler-Lagrange or state-space); 2) Derive optimal state feedback gains using Riccati equations; and 3) Know why each gain has the value it does. Here's an introduction to [LQR](DOCS/learn_LQR.md). 

### DEETS
**Teensy code:** [here](https://github.com/owhite/MESC_brain_board/tree/main/teensy40/PID_position)

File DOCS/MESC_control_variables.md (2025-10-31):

# MESC Motor Control Variables
A listing of variables in the [MESC firmware](https://github.com/davidmolony/MESC_Firmware) that are particularly relevant to balancing. 

### 🔹 Input & Control Variables

- **`UART_req`**  
  - Main user input variable.  
  - Written from **UART commands** or **CAN handlers** (`CAN_ID_ADC1_2_REQ`, `CAN_ID_IQREQ`).  
  - Passed into `MESCinput_Collect()` and merged into `FOC.Idq_req.q`.  
  - Typically treated as normalized `[-1.0 … +1.0]`, then scaled by `max_request_Idq.q` / `min_request_Idq.q`.

- **`remote_ADC1_req` / `remote_ADC2_req`**  
  - Populated from **`CAN_ID_ADC1_2_REQ`** packets.  
  - Mirror the function of physical ADC throttle inputs but come via CAN.  
  - Flow into the same path as throttle inputs.

- **`remote_Iq_req`**  
  - Intended variable for remote torque/current commands via CAN (`CAN_ID_IQREQ`).  
  - In your firmware branch, this was bypassed and written directly to `UART_req` instead.  
  - Author’s style suggests `remote_Iq_req` is the canonical variable.

- **`remote_ADC_timeout` / `remote_Iq_timeout`**  
  - Countdown timers reset whenever a new CAN packet arrives.  
  - If they expire (no packets for a few cycles), input is invalidated → ESC zeros the torque command for safety.

- **`FOC.Idq_req.q`**  
  - Final **q-axis current request** (in amps).  
  - This is what the inner current control loop actually tries to track.  
  - Computed inside the control loop from inputs (`UART_req`, speed loops, etc.).  
  - Should **not** be written to directly from CAN/UART — it gets overwritten each cycle.

- **`max_request_Idq.q` / `min_request_Idq.q`**  
  - Configured current limits (positive/negative).  
  - Define the maximum torque the ESC will ever command.  
  - All normalized requests (`UART_req`, `remote_ADC`) are scaled by these bounds.

- **`mtr[0]->FOC.enc_angle`**  

  - A 16-bit fixed-point mechanical angle, derived from the encoder timer’s CNT, scaled so that it runs 0–65536 per cycle, and resynchronized by the encoder’s Z-pulse via CCR1. 
  - `mtr[0]->FOC.enc_angle` is calculated as:
  - enc_angle=pole_pairs×enc_ratio×(CNT−CCR3)+offset
  - `CNT` gives the live position, while `CCR3` (index pulse latch) ensures the angle resets to a known reference once per mechanical revolution.
  - `CNT` → current quadrature count (mechanical position since last Z).
     - → This provides the absolute reference point per revolution.
  - Relative count
      - (`CNT` - `CCR3`) → ticks since last Z-index pulse.
  - `enc_ratio` converts raw encoder ticks → fixed-point [0…65536] mechanical rev.
  - Then multiplied by `pole_pairs` → converts to magnetic motor position.
  - If `encoder_polarity_invert` is set, it flips the direction by subtracting from 65536.
  - `enc_offset` allows calibration of zero-angle alignment (phase alignment between encoder mechanical zero and motor electrical zero).

- **`mtr[0]->FOC.abs_position`**

    Created for this project. Notice this code addition:
    ```c
	#ifdef POSVEL_PLANE
    if(_motor->FOC.encoder_polarity_invert){
        // Invert direction for abs_position as well
        _motor->FOC.abs_position = ((uint16_t)(_motor->enctimer->Instance->CCR3) - (uint16_t)(_motor->enctimer->Instance->CNT)) & 0x0FFF; // 12-bit wrap
    } else {
        _motor->FOC.abs_position = ((uint16_t)(_motor->enctimer->Instance->CNT)  - (uint16_t)(_motor->enctimer->Instance->CCR3)) & 0x0FFF; // 12-bit wrap
    }
    #endif
    ```
  - The raw mechanical encoder position (0–4096) adjusted to an absolute reference using the Z-pulse (`CCR3`)
  - `FOC.abs_position → ( (uint16_t)(CNT) - (uint16_t)(CCR3) ) & 0x0FFF;` // for 12-bit encoder
  - `CNT` → current encoder count (0–4095).
  - `CCR3` → latched value of CNT when the Z-pulse occurred.
  - `(CNT - CCR3)` → ticks since the last index (Z-pulse).
  - Note: if it wasnt obvious already 4095 is hardcoded all over the place in MESC.

---

# Current MESC Settings

| Parameter | Value |
| --- | --- |
| adc1 | 640 |
| adc1_max | 2700 |
| adc1_min | 500 |
| adc1_pol | 1.000000 |
| adc2_max | 4095 |
| adc2_min | 1200 |
| adc2_pol | 1.000000 |
| can_adc | 3 |
| ehz | -0.283872 |
| error | 0 |
| error_all | 0 |
| FOC_Advance | 0.000000 |
| FOC_angle | 40500 |
| FOC_curr_BW | 3000.000000 |
| FOC_enc_ang | 40500 |
| FOC_enc_oset | 40500 |
| FOC_enc_pol | 1 |
| FOC_enc_PPR | 4096 |
| FOC_flux_gain | 0.367423 |
| FOC_flux_gain | 0.367423 |
| FOC_flux_nlin | 5000.000000 |
| FOC_fpwm | 20000.000000 |
| FOC_fw_ehz | 0.000000 |
| FOC_hall_array_ok | 0 |
| FOC_hall_iir | 0.950000 |
| FOC_hall_Vt | 2.000000 |
| FOC_hfi_eHz | 0.000000 |
| FOC_hfi_type | 1 |
| FOC_hfi_volt | 1.000000 |
| FOC_Max_Mod | 0.950000 |
| FOC_obs_type | 1 |
| FOC_ol_step | 10 |
| FOC_ortega_gain | 1000000.000000 |
| Hall_flux | Array[12] |
| id | -0.007379 |
| input_opt | 32 |
| iq | -0.000819 |
| iqreq | 0.000000 |
| meas_cl_curr | 8.500000 |
| meas_curr | 20.000000 |
| meas_volt | 4.000000 |
| node_id | 12 |
| opt_app_type | 0 |
| opt_circ_lim | 2 |
| opt_cont_type | 0 |
| opt_fw | 2 |
| opt_hall_start | false |
| opt_lr_obs | false |
| opt_motor_temp | false |
| opt_mtpa | 0 |
| opt_phase_bal | false |
| opt_pwm_type | 0 |
| par_dir | 0 |
| par_flux | 0.001350 |
| par_fw_curr | 0.000000 |
| par_i_max | 50.000000 |
| par_i_min | -50.000000 |
| par_i_park | 0.000000 |
| par_ibat_max | 10.000000 |
| par_ld | 0.000015 |
| par_lq | 0.000022 |
| par_motor_sensor | 4 |
| par_p_max | 3000.000000 |
| par_pp | 14 |
| par_r | 0.070000 |
| par_rpm_max | 0 |
| par_SL_sensor | 0 |
| password | |
| safe_count | 100 |
| safe_start | 100 |
| speed_ki | 0.100000 |
| speed_kp | 0.500000 |
| speed_req | 0.000000 |
| TMOS | 299.611572 |
| TMOT | 199.968307 |
| uart_dreq | 0.000000 |
| uart_req | 0.000000 |
| vbus | 29.723145 |
| Vd | -0.004284 |
| Vq | 0.006748 |

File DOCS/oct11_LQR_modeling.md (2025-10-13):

## Oct 11, 2025
# Pendulum Model Validation
## Recap of a system that failed:

Attempt: Python + Trimesh + PyBullet workflow to:
- Calculate the **total mass**, **center of mass**, and **moment of inertia** for a pendulum assembly.
- Export a **URDF** with correct joint reference alignment.
- Generate a **JSON file** with all derived quantities for **LQR control** and **physics verification**.

### Program Outputs

From CAD → JSON input, the script now produces:
- ✅ `pendulum_assembly.urdf`  
  - Contains the correctly referenced joint pivot and adjusted visual origins.
- ✅ `pendulum_LQR_data.json`  
  - Contains:

| Variable | Description |
|---|---|
| `mass_kg` | Total pendulum mass |
| `moment_of_inertia_kg_m2` | Scalar moment of inertia about rotation axis |
| `r_m` | Pivot-to-CoM distance |
| `mgr_over_I` | Gravitational stiffness term |
| `omega_n_rad_per_s` | Natural angular frequency |
| `expected_period_s` | Small-angle oscillation period |
| `A_matrix`, `B_matrix` | Linearized state-space model |

---

## If successful verification would have been

**verify and challenge the model’s accuracy**.

### 1. Analytical Validation
- Confirm \( I \approx m r^2 \) is within a reasonable range.
- Recalculate \( \omega_n = \sqrt{mgr/I} \) manually from JSON and verify consistency.
- Perform unit sanity checks.

### 2. Simulation Validation
- Load the generated URDF into PyBullet.
- Apply a small initial angle and simulate free fall.
- Measure the oscillation period and compare to theoretical \( T = 2\pi/\omega_n \).
- Plot or print the ratio \( T_{sim} / T_{theory} \).

### 3. Error Analysis
- Identify whether errors originate from:
  - STL alignment (pivot mismatch)
  - Density inaccuracies
  - Incorrect unit scaling
  - Numerical instability in inertia computation

### 4. Deliverables for Verification
- Python script to simulate free oscillation and extract period.
- Comparison table between theoretical and simulated values.
- Optional visual overlay in PyBullet showing pivot, CoM, and rotation axis.

---

# Inventory of tools:

## 1. Geometry & Input Stage
| Program/File | Purpose | Notes |
|---|---|---|
| **CAD Program** (e.g. dump_stls.py) | Designs pendulum components and assembly | Exports `.stl` files in **global coordinates** (critical for alignment) |
| **Exported STL files** | Geometry for each part (`housing.stl`, `steel.stl`, etc.) | Units in **mm**, placed correctly in global CAD frame |
| **CAD → JSON exporter** | Produces metadata describing:  <br>• `file_path` <br>• `meshes` (filenames & densities) <br>• `axis_of_rotation` <br>• `origin` | This JSON is the *starting input* to the analysis pipeline |

Example input JSON:
```json
{
  "file_path": "/Users/owhite/Downloads/",
  "meshes": {
    "part1.stl": { "density": 2700.0 },
    "part2.stl": { "density": 7850.0 }
  },
  "axis_of_rotation": [0.0, 1.0, 0.0],
  "origin": [0.0, 0.0, 400.0]
}
```

---

## 2. Physical Property Calculation
| Program | Filename | Purpose |
|---|---|---|
| **Inertia and URDF Generator** | `pybullet_generator.py` | Main script that: <br>• Loads STL meshes using **Trimesh** <br>• Calculates total mass, CoM, and inertia <br>• Generates `pendulum_assembly.urdf` and `pendulum_LQR_data.json` |
| **Dependencies** | `trimesh`, `numpy`, `json`, `os`, `xml.etree.ElementTree`, `minidom` | No custom external data beyond STL + JSON input |

### Outputs
1. ✅ **URDF file** (`pendulum_assembly.urdf`) — used by PyBullet  
2. ✅ **JSON file** (`pendulum_LQR_data.json`) — for LQR and model validation  

---

## 3. Simulation and Visualization
| Program | Filename | Purpose |
|---|---|---|
| **PyBullet Visualizer** | `display_urdf.py` | Opens the URDF in **PyBullet GUI**, renders ground plane, origin axes, joint axis, and verifies correct pivot position |
| **PyBullet Environment** | Installed in Conda env (`pybullet-env`) | Used for 3D physics simulation, free-swing test, and debugging URDF alignment |
| **plane.urdf** | Included from `pybullet_data` | Ground reference to visualize z=0 plane alignment |

### Visualization Features
- Draws red/green/blue **world axes**
- Draws **yellow line** for the pendulum joint axis
- Marks the **pivot** with a small sphere
- Prints joint origin and axis vectors for debug alignment

---

## 4. Environment Setup for pybullet
| Tool | Purpose |
|---|---|
| **Conda Environment** (`pybullet-env`) | Isolated Python environment containing:  <br>`pybullet`, `trimesh`, `numpy`, `matplotlib` |
| **Command examples** |  |
| Create: `conda create -n pybullet-env python=3.11`  |
| Activate: `conda activate pybullet-env`  |
| Install: `pip install pybullet trimesh numpy matplotlib`  |

---

## 🧠 Workflow Summary
```plaintext
CAD (STLs) 
   ↓
dump_stls.py CAD Export JSON (file paths, densities, axis, origin)
   ↓
pybullet_generator.py
   ├── computes mass, CoM, inertia
   ├── generates URDF (adjusted for joint reference)
   └── writes LQR + validation JSON
   ↓
display_urdf.py (PyBullet) NOTE: this was tossed out later
   ├── loads URDF
   ├── visualizes pivot and CoM alignment
   └── prepares for dynamic validation
   ↓
Next: simulate free swing → extract period → verify ωₙ consistency
```
---

## So anyway, ignore all that:

There are many problems with using pybullet, I repeatedly saw that:
- PyBullet ignored the <inertial> block unless carefully loaded with obscure flags (URDF_USE_INERTIA_FROM_FILE),
- it silently recalculated inertia from collision shapes,
- it shifted or re-centered links internally based on mesh origins.
- never had full control over the COM or pivot alignment — exactly the things your controller depends on.
- juggling local vs. world COM frames sucked

Quote from ChatGPT: *“What you’ve been doing for days is the kind of debugging that makes seasoned robotics PhDs question their life choices.”*

I'm giving up on that for now, but at least have created a script to get the LQR state model:

```
$ ./generatfe_LQR_data.py pendulum_metadata.json
```

which generates `pendulum_LQR_data.json`

Have a look for good numbers using:

```
$ ./verify_LQR_data.py pendulum_LQR_data.json 
```

Check:
- Mass (0.193 kg) → plausible for the pendulum.
- Inertia (4.9×10⁻³ kg·m²) → matches Trimesh computation
- Lever arm (0.089 m) → correctly converted from 89 mm.
- Gravity (9.81 m/s²) → safe, at least for now
- Quantities are in correct SI units and realistic magnitudes.
- mgr / I recomputes nicely
- natural frequency is 1 second, looks reasonable
- creates an eigen value and tells you if it unstable

Then this thing makes input for the teensy, supposedly:
```
$ ./design_pendulum_LQR.py pendulum_LQR_data.json
```

---
## DEETS
- git hash ID: 402ffd1dfd508cb03787e4157f761a6df67d2a21

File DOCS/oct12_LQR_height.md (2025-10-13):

## Oct 12, 2025
# Pendulum Model Height

## Pendulum Control Bandwidth and Implications for Balancing Robot

During testing of the inverted pendulum system, the LQR controller produced stable but sluggish responses, even when control effort (R value) was reduced or motor torque increased. The limiting factor was identified as the relationship between the pendulum’s physical dynamics and the controller’s update rate.

For the test configuration:
- Length (pivot to COM): ≈ 0.13 m
- Mass: ≈ 0.19 kg
- Moment of inertia: ≈ 4.9 × 10⁻³ kg·m²
- Natural frequency: ≈ 5.9 rad/s (≈ 1.1 s period)
- Control loop: 500 Hz (2 ms sampling period)

This configuration resulted in a slow plant (long period, weak torque leverage) controlled by a moderately fast digital loop. Because torque authority and gravitational restoring forces were small, the controller could not strongly influence the state between samples—making the response appear “sluggish” despite increased LQR gains.

When the pendulum length is shortened (≈ 0.07 m), the natural frequency increases (~20 rad/s), and the control authority improves substantially. A shorter pendulum is easier to stabilize digitally because its dynamics operate well within the controller’s effective bandwidth.

This outcome is opposite to human intuition: a tall broomstick is easier for a person to balance because human reaction time is slow, whereas a digital controller benefits from a faster, more responsive plant.

## According to ChatG...
For the two-wheel balancing robot, this limitation is far less severe:

- The robot’s actuation (wheel acceleration) directly moves the base under the COM, giving much greater control authority.
- The 500 Hz loop frequency is adequate for body dynamics in the 15–50 rad/s range, typical for small robots.
- Stability will instead depend on motor torque limits, mechanical delay, and COM height—not on sample rate alone.

In summary:

The hanging pendulum revealed that long, slow plants are difficult to dominate with discrete-time control.
For the balancing robot, faster actuation and lower COM ensure the same 500 Hz controller will perform effectively.

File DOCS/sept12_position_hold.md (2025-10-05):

## sept 12, 2025
# Attempts at position hold

## Next thing
You want to implement a **motor position-hold test**:  
- Detect RC input stick deflection on channel 0.  
- When deflected beyond ±100 µs from center (1500 µs), capture the current motor position as a target.  
- Run a **PD loop** each tick to hold that position:  
  ```cpp
  torque = Kp * (target_pos - current_pos) + Kd * (0 - current_vel);
  ```  
- Send torque command to ESC via CAN IQREQ message.  

## 🔹 Code Integration Notes
- In `supervisor.cpp`, inside `// Core control loop body`, you will insert the position-hold PD logic.  
- `ESC` already has a `node_id`, but it lives in `esc[i].config.node_id`, not `esc[i].node_id`.  
- Use:  
  ```cpp
  msg.id = canMakeExtId(CAN_ID_IQREQ, TEENSY_NODE_ID, sup->esc[0].config.node_id);
  ```  
- Be sure to `#include "CAN_helper.h"` in `supervisor.cpp`.  
- Replace `Can1.write(msg)` with `can.write(msg)` (since `controlLoop` already receives `can` as a parameter).  

## 🔹 Position Hold (definition)
“Position hold” = when the robot detects an RC input deflection, it captures the motor’s current encoder position as a reference, and uses a PD controller to apply torque so that the motor resists being moved away from that reference (like an electronic spring-damper lock).  

---

## 🔹 Starter Code Block for Position Hold

Insert this into `supervisor.cpp` where you see `// Core control loop body`:

```cpp
    // ---- Core control loop body ----

    static bool holding = false;
    static float hold_pos_rad = 0.0f;

    // Detect RC stick deflection on channel 0 (raw PWM, ~1500 ± 100 deadband)
    if ((sup->rc_raw[0].raw_us > 1600) || (sup->rc_raw[0].raw_us < 1400)) {
        if (!holding) {
            // First time deflected → capture hold position
            hold_pos_rad = sup->esc[0].state.pos_rad;
            holding = true;
        }
    } else {
        holding = false;
    }

    if (holding) {
        // PD control: torque = Kp*error + Kd*error_dot
        float pos_err = hold_pos_rad - sup->esc[0].state.pos_rad;
        float vel_err = 0.0f - sup->esc[0].state.vel_rad_s;

        const float Kp = 2.0f;   // tune gains
        const float Kd = 0.1f;

        float cmd_torque = Kp * pos_err + Kd * vel_err;

        // Build CAN IQREQ packet
        CAN_message_t msg;
        msg.id = canMakeExtId(CAN_ID_IQREQ,
                              TEENSY_NODE_ID,
                              sup->esc[0].config.node_id);
        msg.len = 8;
        msg.flags.extended = 1;

        canPackFloat(cmd_torque, msg.buf);
        canPackFloat(0.0f, msg.buf + 4);  // second float unused

        // Send to CAN bus via passed-in reference
        can.write(msg);
    }
```

## Bottom line

- This works like shit. 
- Nothing to see here. 
- Move on. 
- What you learned [here](sept18_controller_issues.md) and elsewhere is PID on an unloaded motor sucks

---

### DEETS
**Teensy code:** [here](https://github.com/owhite/MESC_brain_board/tree/main/teensy40/hold_position_test)

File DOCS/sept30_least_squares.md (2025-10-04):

## Sept 30, 2025
# Workflow: From Rhino to PyBullet

## 1. Geometry Design in Rhino
- Create the pendulum or robot parts as 3D CAD geometry in **Rhino**.
- Use Rhino to include densities of each part:
   - "Window->Floating panels->Document user text panel".
- Keep geometry clean and simplified (avoid unnecessary detail that would inflate the mesh).
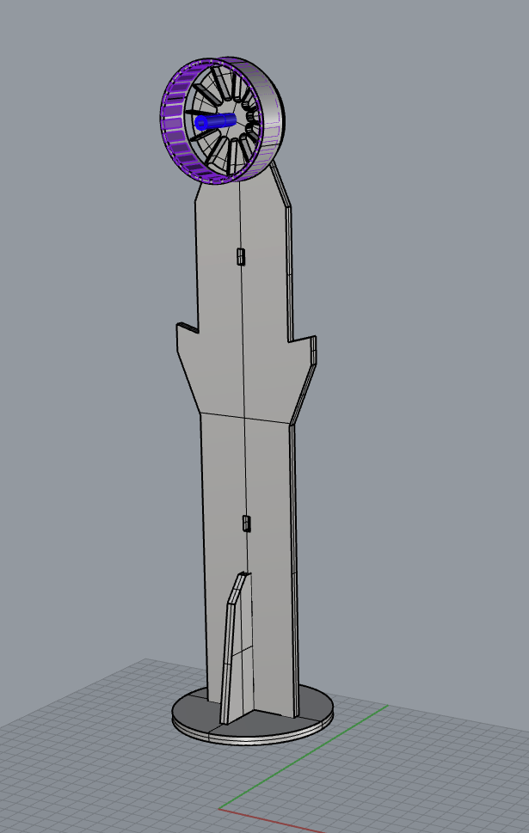
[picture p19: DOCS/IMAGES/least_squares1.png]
Plot result


## 2. Export to STL
- Export each part as an **STL file** in Rhino using dump_stls.py
- Use consistent units (e.g., meters) to avoid scale mismatches in PyBullet.
- Check mesh orientation (positive Z usually up in PyBullet).
```
$ ./pybullet_generator.py pendulum_metadata.json 
```

- Output should include:
  - pendulum_metadata.xml
  - pendulum.urdf 
  - model_debug.json

## 3. Load Meshes in PyBullet
- Import STL files into PyBullet via `createCollisionShape` and `createVisualShape`.
- Evaluate meshes with tools like **trimesh** 
- Bundle STL parts into a **URDF** file to define joints, masses, and inertial properties.

A baby modeling example of parts that are in pendulum.3dm:
```
 ./sinusoidal1.py 
```

# Next Steps for Pendulum Validation & Modeling

some initial modeling is [here](https://youtu.be/Mqh3uTG2mss). 

so what am I thinking about now? 

### PRBS torque input
- Use Pseudorandom Binary Sequence torque input to test signal that excites many frequencies in the system.
- Useful for system identification, because it gives enough variation to estimate parameters robustly.

### Least Squares
- Use least squares to compare the physical model vs. the theoretical one.
- Commonly used to fit parameters (like damping or inertia) by minimizing the error between measured output (pendulum angle, velocity) and model predictions.

### Validation plan
- apply a known torque, see how the pendulum moves, and check if the real torque response is “in the ballpark” of the theoretical torque.
- a straightforward sanity check before doing full system ID.

### Summary of your modeling plan
- Step 1: Actuate the pendulum with known torque (via ESC command).
- Step 2: Measure motion (angle, velocity).
- Step 3: Compare observed vs. predicted trajectory.
- Step 4: Later, add more structured inputs (PRBS) and use least squares fitting to refine model parameters.

### Set up experiment
- Connect pendulum to ESC/motor.
- Ensure we can send torque commands reliably.

### Baseline test
- Apply a simple constant torque (via ESC).
- Record pendulum motion (angle, velocity).
- Compare observed motion with theoretical model predictions.

### Structured excitation
- Use step torques, sine sweeps, or PRBS signals for richer input data.
- Collect multiple datasets to capture system behavior across conditions.

### Model fitting
- Apply least squares to minimize error between measured response and model output.
- Estimate parameters (e.g., inertia, damping, stiffness).

### Validation
- Run new experiments with different inputs.
- Check if refined model predicts responses accurately.

### Iteration
- Adjust experimental design (inputs, sampling) as needed.
- Refine model complexity (linear vs nonlinear terms) if discrepancies remain.

### Deets
- **commit hashID:** 98ba801e7c58266692fff25def08ca7ed19e4dcc
- **Pendulum Rhino3D model:** [LINK](https://github.com/owhite/MESC_brain_board/blob/main/modeling/pendulum.3dm)

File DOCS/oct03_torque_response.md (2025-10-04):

## Oct 03, 2025
## Modeling the Pendulum in PyBullet

### We have a full workflow:
- Create 3D objects in Rhino3d. 
- Export STLs to disk. 
- Model the parts mass/inertia in PyBullet.
- Predict torque requirements and timing in simulation.
- Drive the real pendulum by sending commands to MESC.
- Collects real data via serial.
- See: [least_squares](sept30_least_squares.md)

### STL meshes were exported from Rhino3D and built a URDF description of the pendulum, including:
- Mass and inertia tensors (computed from STL volume/density).
- Center of mass offsets.
- A hinge joint defined at the top of the pendulum.
- A [modeling program](https://www.youtube.com/watch?v=Mqh3uTG2mss) visualizes both the joint position and center of mass (COM).
- Torque simulations uses PyBullet to life the pendulum
- Result: the simulation predicted ~150–220 ms to swing through a quarter turn with ~0.6 Nm

### Testing the physical system:
- Send current commands to the ESC (via serial JSON messages), see: [this video](https://youtube.com/shorts/aiBLkrTjKmU)
- Data from the Teensy logs torque, position, and velocity.
- Live plotting using Matplotlib animation:
- User sets: 
  - Torque constant (Kt).
  - Requested torque (Nm).
  - Pulse duration.
  - Total experiment time.

Launch the graphing program
```
$ ./torque_raise.py  /dev/cu.usbmodem178888901
```

Plot result

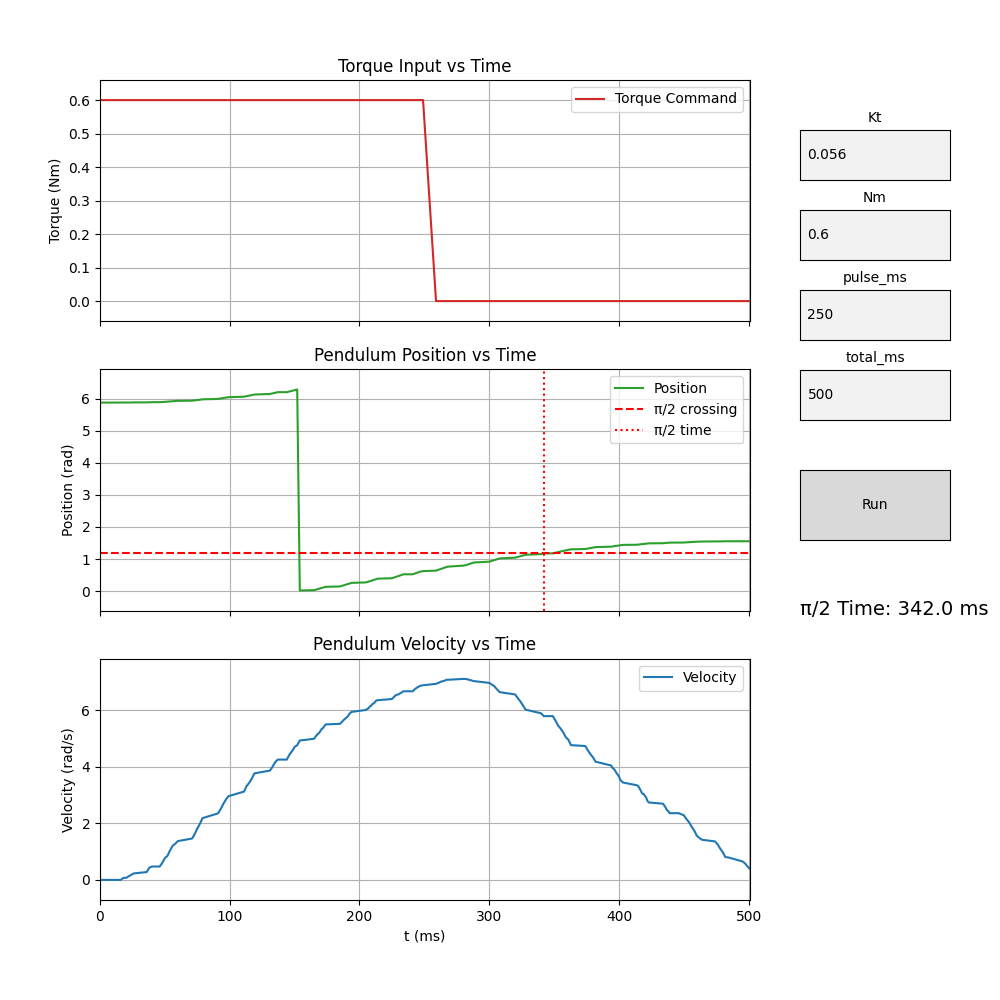
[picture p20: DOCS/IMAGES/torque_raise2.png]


### Outcome: 
- The plot shows amount of time to get the pendulum to 9 o'clock position. 
- Note: in this case I added extra weight to the pendulum
- Shows torque is assymetric. note:
  - (-0.6) Nm takes 303 ms to get to position
  - (+0.6) Nm takes 342 ms to get to position

### Theory v. real-world testing:

**Theoretical rates** for moving the pendulum from downward position
- I=0.00229kg⋅m^2
- τ=0.6Nm
- Ideal time to reach π/2 radians ≈ 0.11 s
- assumes:
  - Constant torque of exactly 0.6 Nm
  - No friction, delay, current limiting, or voltage drop
  - Torque instantaneously applied
- Therefore 110 ms is the ballistic lower bound

**Real-world factors** that influence theory
- At low speed, friction and cogging are significant relative to the small inertia.
- Motor over-coming dead stop threshold before moving.
- ESC current-loop bandwidth
  - current controller (PI loop) 
  - CAN command update rate
  - Voltage sag and back-EMF
- Pendulum geometry, air drag
- Measurement lag

**According to chatGPT** these factors are in play: 

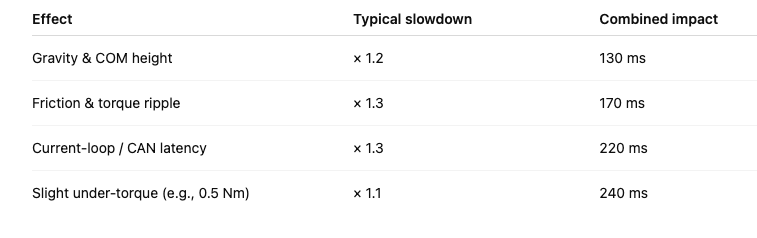
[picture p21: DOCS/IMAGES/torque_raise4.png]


Which is to say, **predicted realistic time ≈ 240–260 ms**

So let's look at what we get: 

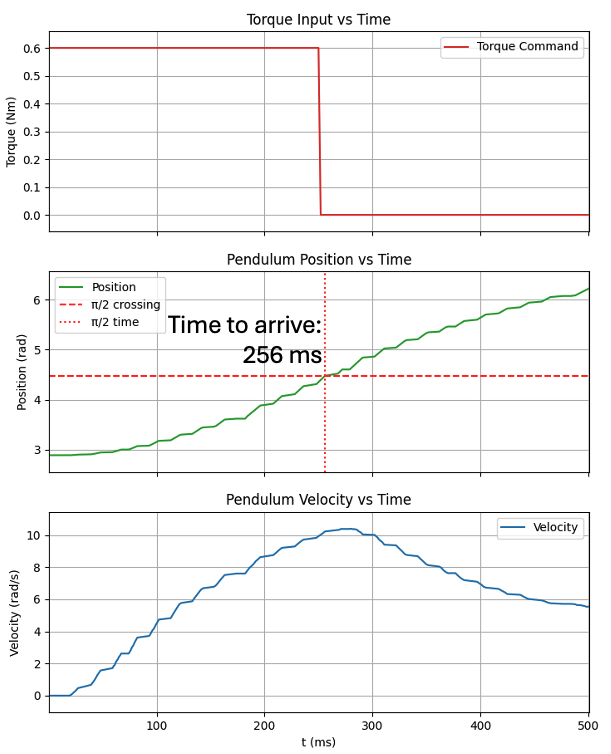
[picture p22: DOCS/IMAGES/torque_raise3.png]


---
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

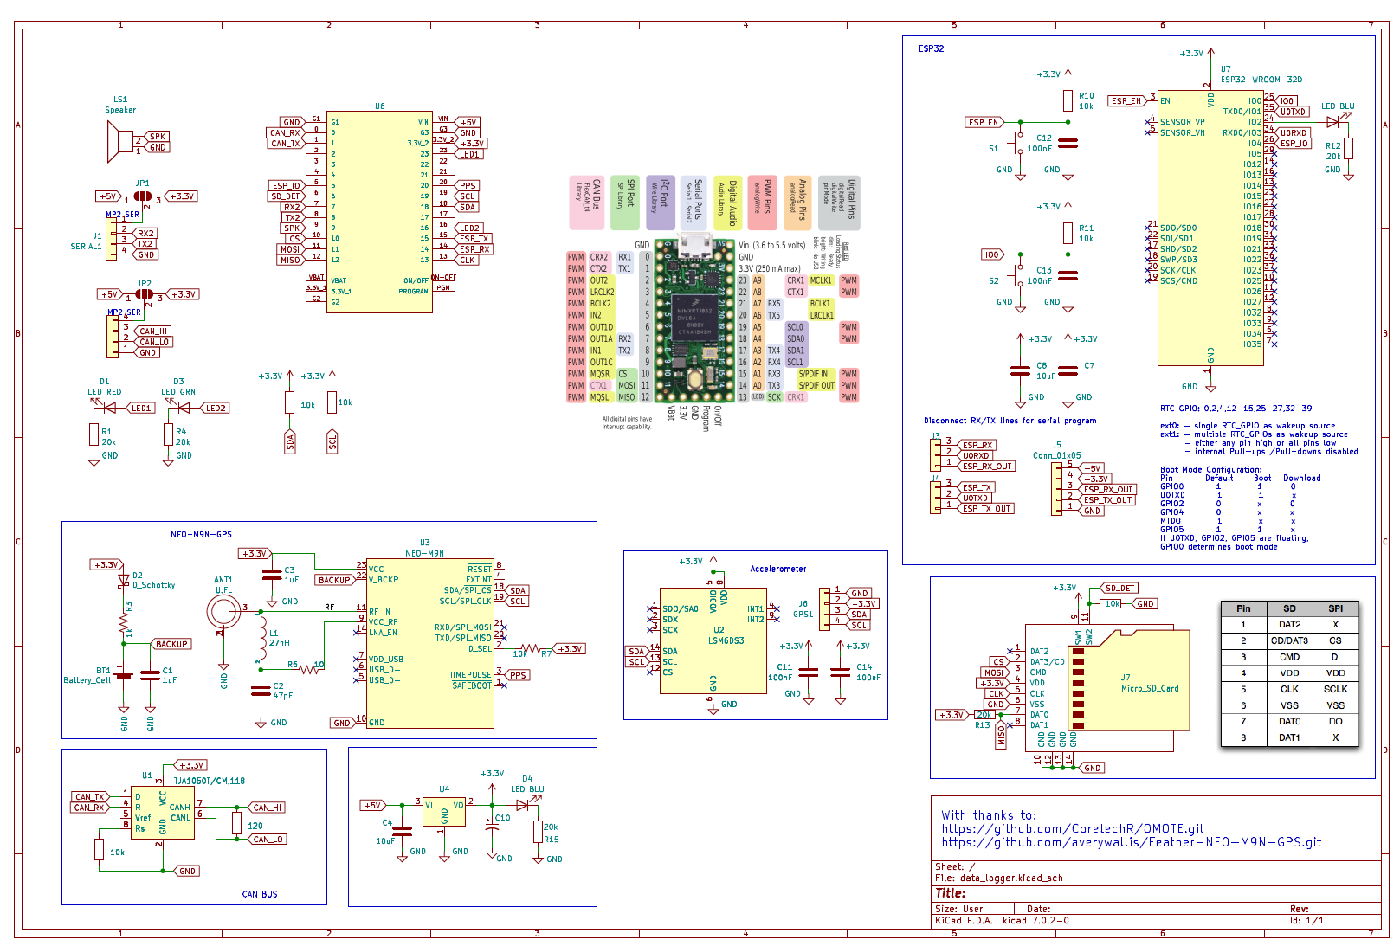
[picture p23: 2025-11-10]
PCBs/brainboardV1.2/schematic.png

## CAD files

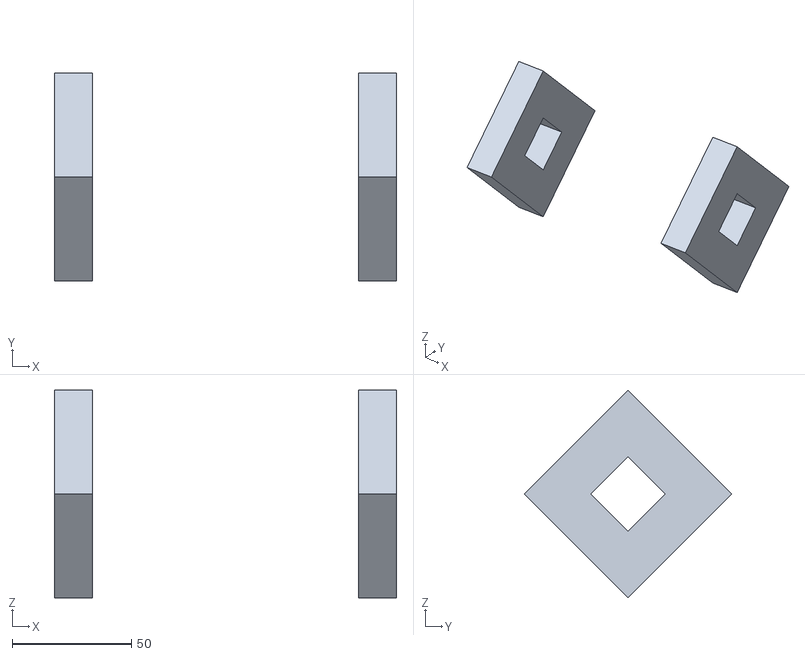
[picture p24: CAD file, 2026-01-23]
modeling/data/GL80/rotors.stl
143.2 x 87.0 x 87.0

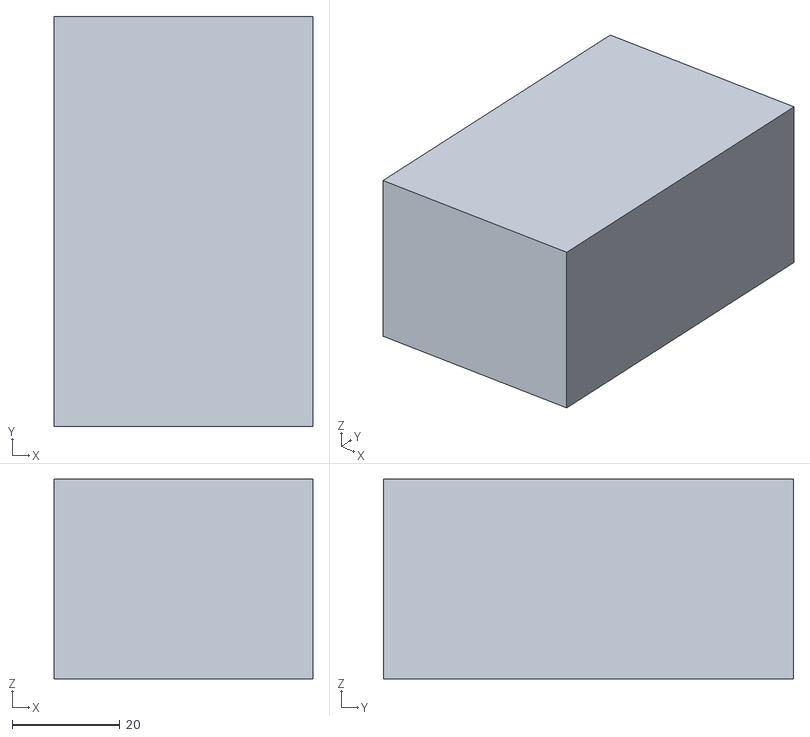
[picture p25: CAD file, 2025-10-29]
modeling_devel/battery.stl
48.0 x 76.0 x 37.0

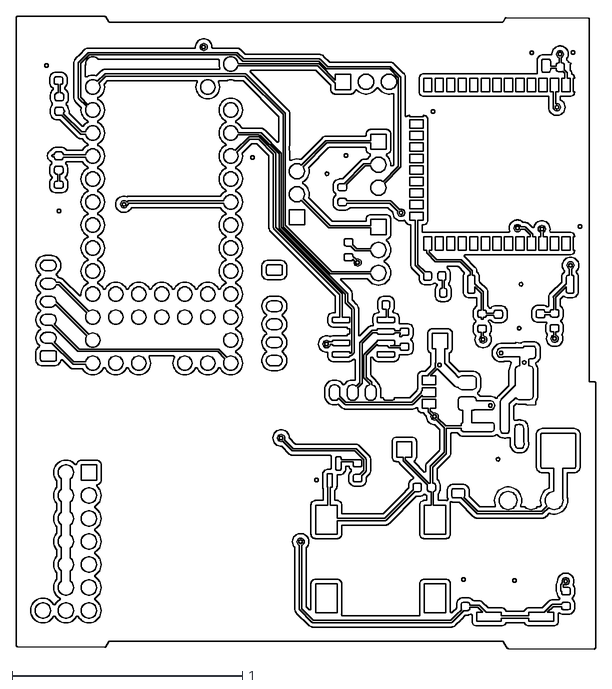
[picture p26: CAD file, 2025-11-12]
PCBs/brainboardV1.2/DXFs/MESC_brain_board-F_Cu.dxf
2.52 x 2.75

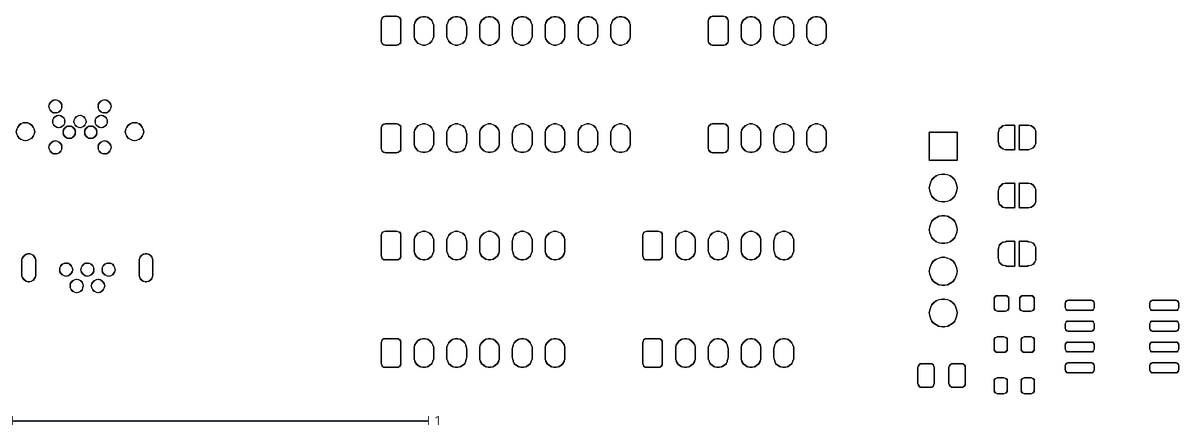
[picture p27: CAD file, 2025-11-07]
PCBs/ESC_caddyV1.0/DXF/ESC_caddyV1.0-F_Cu.dxf
2.79 x 0.905

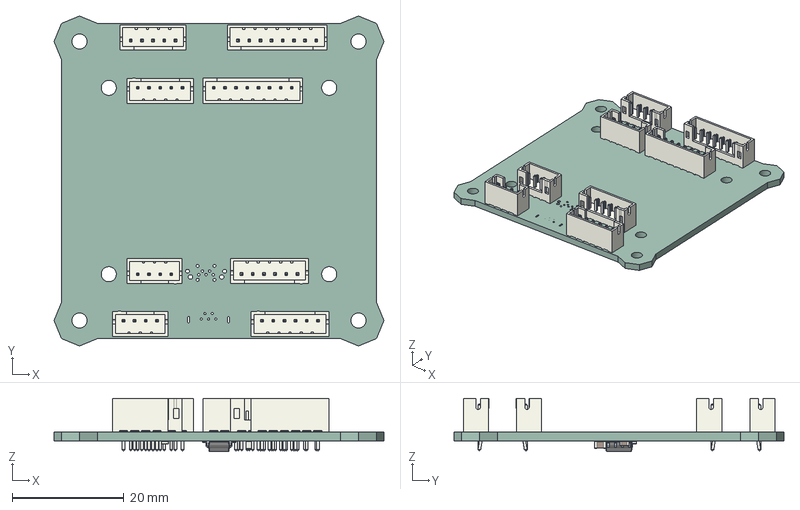
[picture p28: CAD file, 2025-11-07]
PCBs/ESC_caddyV1.0/ESC_caddyV1.0.step
59.1 x 59.1 x 9.55 mm
JST_B5B_PH_K x 2
JST_B4B_PH_K x 2
JST_B6B_PH_K x 2
JST_B8B_PH_K x 2
R_0603_1608Metric x 2
CQ assembly
C_0805_2012Metric
C_0603_1608Metric
ESC_caddyV1.0_PCB

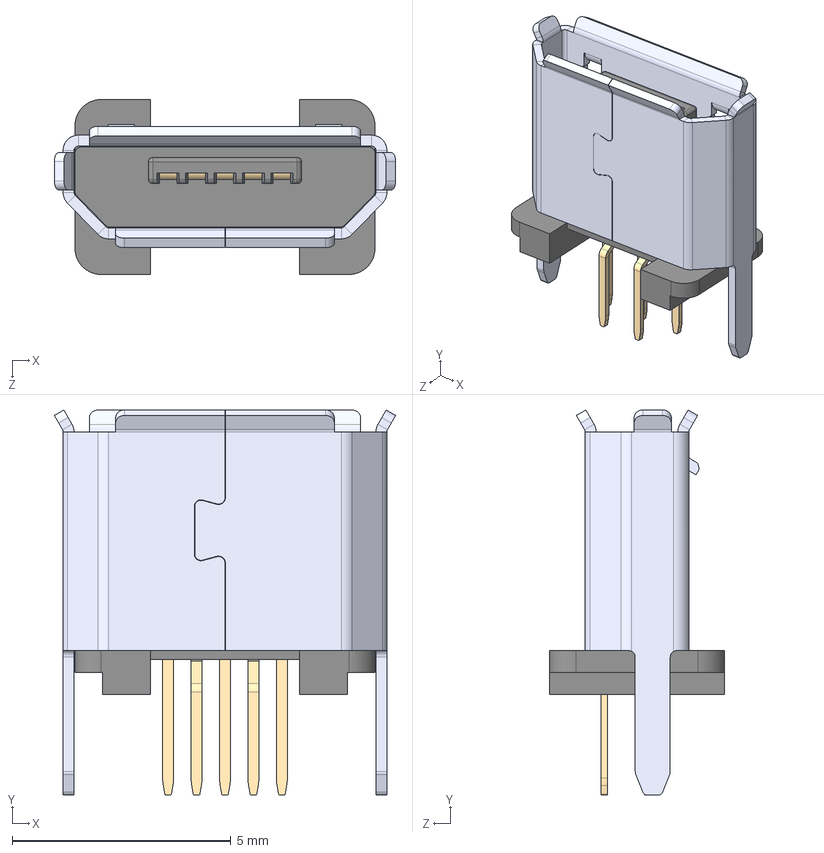
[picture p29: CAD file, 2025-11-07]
PCBs/ESC_caddyV1.0/USB3145-30-1-A/USB3145-30-1-A.step
7.80 x 8.80 x 4.00 mm

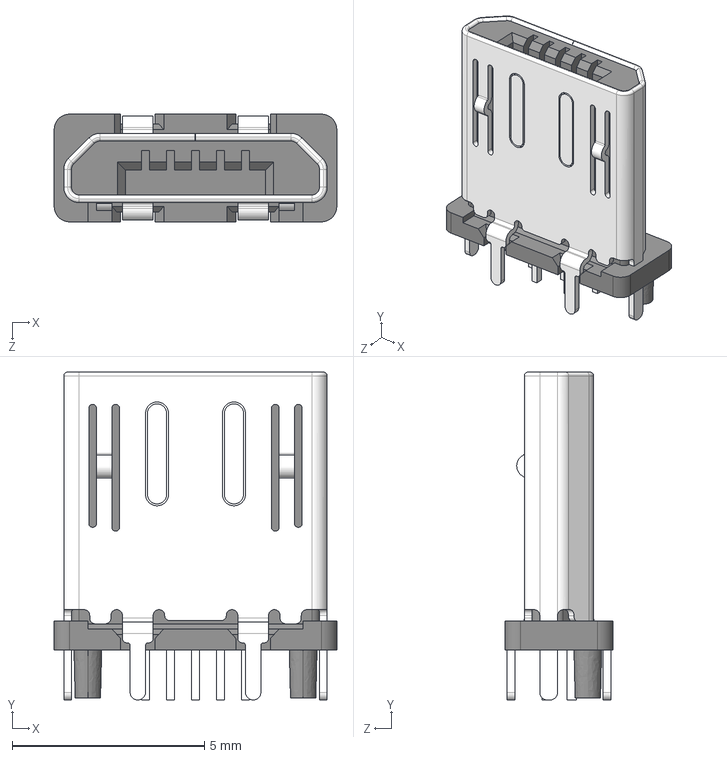
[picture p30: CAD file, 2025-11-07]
PCBs/ESC_caddyV1.0/USB3150-30-130-A/USB3150-30-130-A.step
7.35 x 8.53 x 2.80 mm

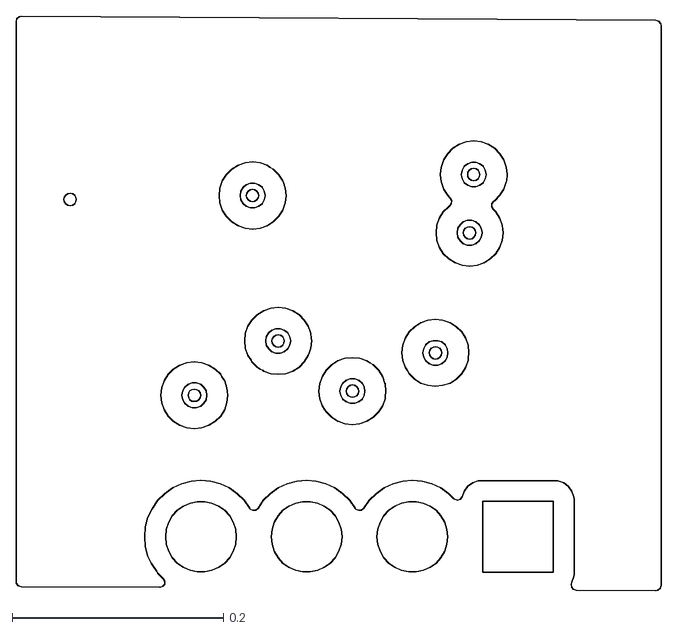
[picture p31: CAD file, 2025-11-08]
PCBs/MT6701_12mm/DXF/MT6701_ENCODER-In2_Cu.dxf
0.61 x 0.543

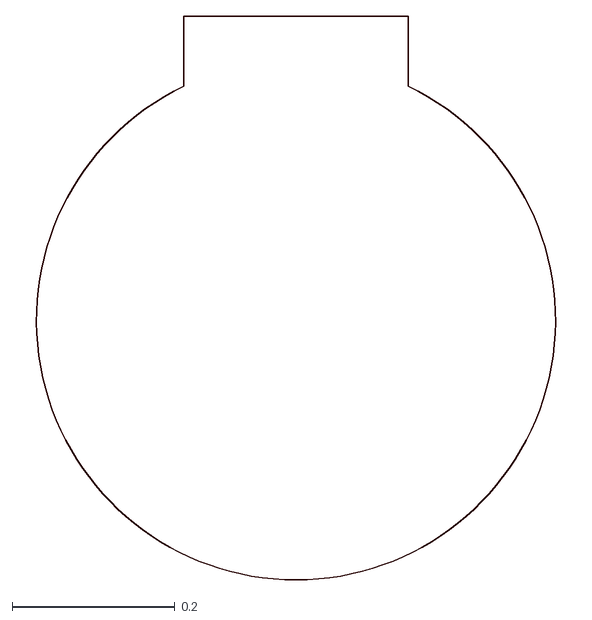
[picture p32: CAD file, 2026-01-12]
PCBs/MT6701_12mm/Untitled.dxf
0.689 x 0.693

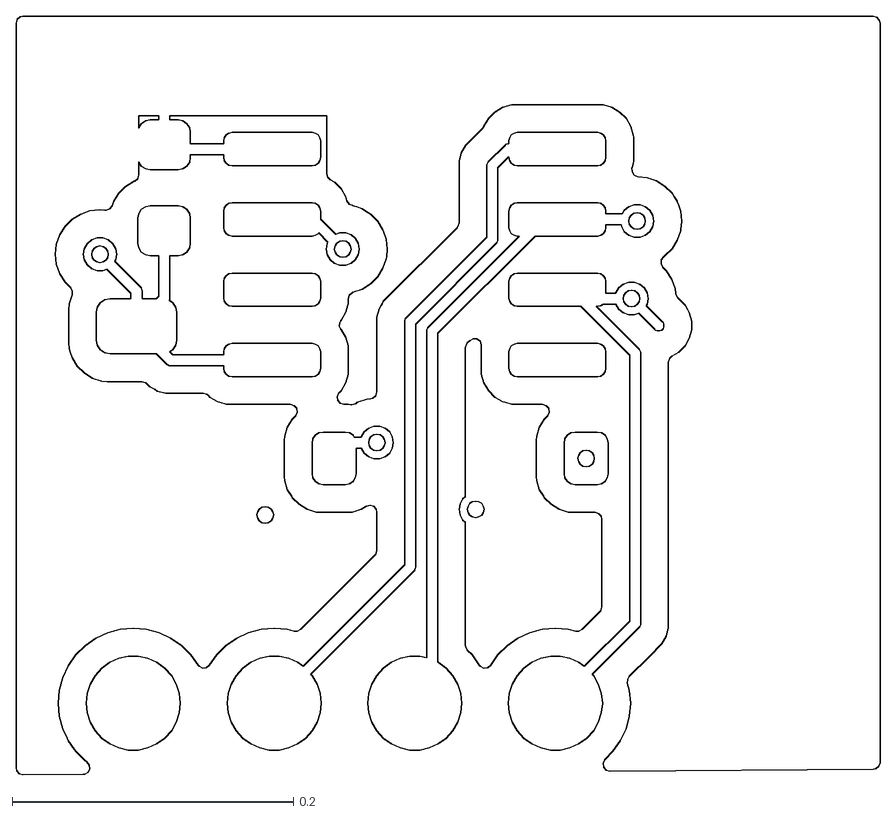
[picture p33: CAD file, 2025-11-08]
PCBs/MT6701_ENCODER/DXF/MT6701_ENCODER-F_Cu.dxf
0.614 x 0.539

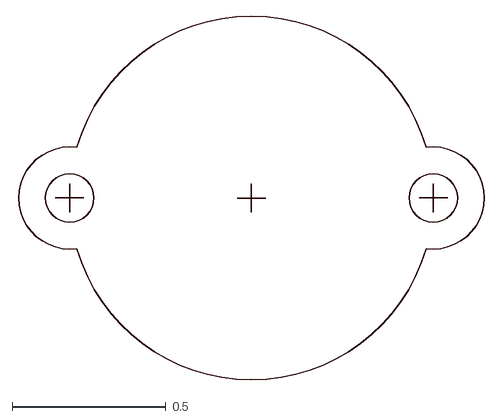
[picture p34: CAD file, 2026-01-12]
PCBs/MT6701_ENCODER/outline.dxf
1.53 x 1.18

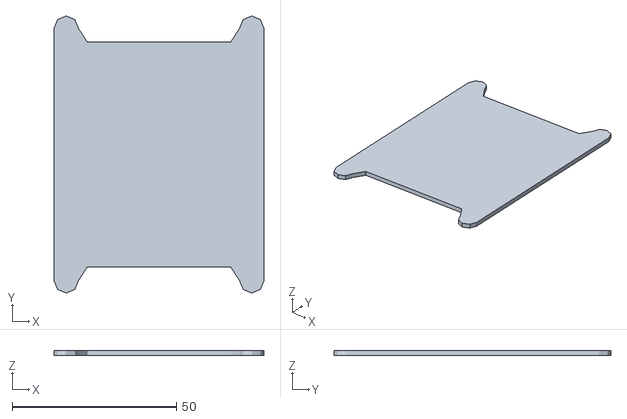
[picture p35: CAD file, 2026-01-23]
modeling/data/GL80/brain_board.stl
63.8 x 84.2 x 1.60

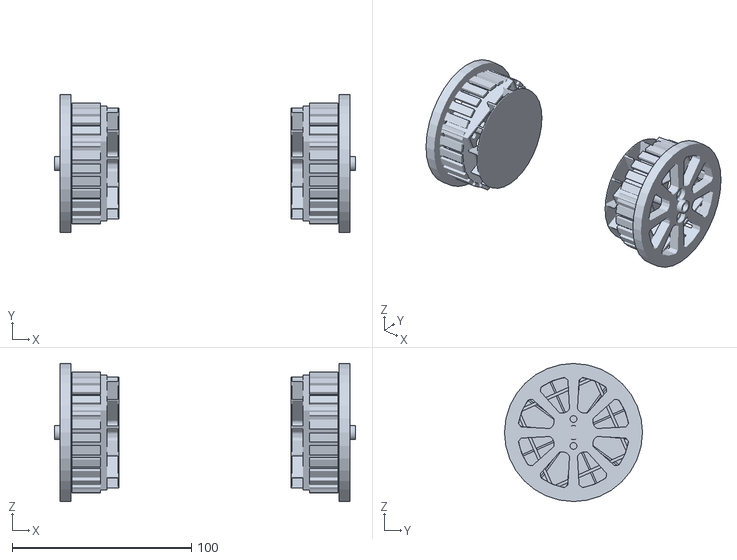
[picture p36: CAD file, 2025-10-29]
modeling_devel/wheels.stl
167.9 x 77.0 x 77.0

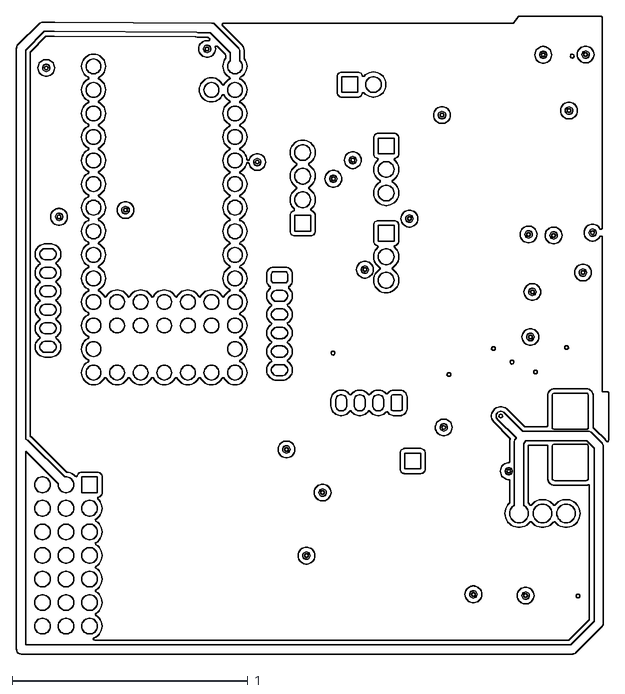
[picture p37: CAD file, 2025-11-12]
PCBs/brainboardV1.2/DXFs/MESC_brain_board-In2_Cu.dxf
2.51 x 2.71

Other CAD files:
PCBs/ESC_caddyV1.0/board_layout.dxf
PCBs/ESC_caddyV1.0/DXF/ESC_caddyV1.0-B_Cu.dxf
PCBs/MT6701_12mm/DXF/MT6701_ENCODER-Edge_Cuts.dxf
PCBs/ESC_caddyV1.0/DXF/ESC_caddyV1.0-B_Mask.dxf
PCBs/ESC_caddyV1.0/DXF/ESC_caddyV1.0-B_Paste.dxf
PCBs/ESC_caddyV1.0/DXF/ESC_caddyV1.0-B_Silkscreen.dxf
PCBs/ESC_caddyV1.0/DXF/ESC_caddyV1.0-Edge_Cuts.dxf
PCBs/ESC_caddyV1.0/DXF/ESC_caddyV1.0-F_Mask.dxf
PCBs/ESC_caddyV1.0/DXF/ESC_caddyV1.0-F_Paste.dxf
PCBs/ESC_caddyV1.0/DXF/ESC_caddyV1.0-F_Silkscreen.dxf
PCBs/MT6701_12mm/DXF/MT6701_ENCODER-B_Cu.dxf
PCBs/MT6701_12mm/DXF/MT6701_ENCODER-B_Mask.dxf
PCBs/MT6701_12mm/DXF/MT6701_ENCODER-B_Paste.dxf
PCBs/MT6701_12mm/DXF/MT6701_ENCODER-B_Silkscreen.dxf
PCBs/MT6701_12mm/DXF/MT6701_ENCODER-F_Mask.dxf
PCBs/MT6701_12mm/DXF/MT6701_ENCODER-F_Paste.dxf
PCBs/MT6701_12mm/DXF/MT6701_ENCODER-F_Silkscreen.dxf
PCBs/MT6701_ENCODER/DXF/MT6701_ENCODER-B_Cu.dxf
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

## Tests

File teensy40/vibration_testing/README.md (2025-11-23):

# Preamble

See [this entry](../../DOCS/nov16_IMU.md) on using a Mahony filter to improve readings from the ICM42688. The filter automatically rejects vibration-induced accelerometer noise and uses gyro bias correction to keep the angle accurate over time. The code used for SPI communications with the ICM42688 was slightly modified from [here](https://github.com/finani/ICM42688.git) and the Mahony filter in [supervisor.cpp](src/supervisor.cpp) in `mahonyUpdateIMU()`. Also have a look at `controlLoop()` in [balance_TWR_mode.cpp](src/balance_TWR_mode.cpp) to get a general idea. This work was done at this commit: hash id: `9633b44677406c790000eb56cd1858c216e7f7b5`

Running `./IMU_test.py -p /dev/cu.usbmodem178888901` created the IMU plots of [this entry](../../DOCS/nov16_IMU.md) 

## It's time to test a few things. 

- Quantify the noise the motor injects into the IMU.
- Verify IMU reports correct angle vs. actual mechanical tilt (see: [this](../../DOCS/nov16_IMU.md))
- Determine whether torque request → torque output is linear and symmetric.
- Verify identical torque commands produce identical reaction torque.
- Check whether identical torque commands produce repeatable motor currents.
- Timing of torque command applied to motor. Use Teensy pin toggle to mark when torque command is sent. Use oscilloscope to measure phase current rise time, voltage behavior, ESC PWM switching pattern. 

## IMU noise

During the process comparing the IMU with the mechanical angle of the wheel encoders I tested this

I put this the code:
```
    float a_mag = sqrtf(ax*ax + ay*ay + az*az);
    Serial.printf("a_mag=%.5f\r\n", a_mag);
```

and when the motor is running, I get these type of values: 
```
a_mag=3.05135
a_mag=5.25944
a_mag=3.85885
a_mag=6.80106
a_mag=3.69635
a_mag=5.77368
a_mag=9.36287
a_mag=10.89755
a_mag=4.79244
a_mag=2.57672
a_mag=8.32236
a_mag=1.29584
a_mag=2.59398
```

That's pretty horrendous. To reduce noise, I changed the FOC PWM from 20,000 to 10,000, and fooled around with physical dampening of the IMU. and used this to view the vibration: 

`./IMU_test.py -p /dev/cu.usbmodem178888901` 

Also, [supervisor.cpp](src/supervisor.cpp) applies a Mahony filter which fuses acceleration  and gyro values from the IMU. I added this code: 

```c
  if (accMag > 1e-6f) {
    float recip = 1.0f / accMag;
    ax *= recip;
    ay *= recip;
    az *= recip;

    if (accMag > 0.85f && accMag < 1.15f) {
      accelValid = true;
    } else {
      accelValid = false;
    }
  }
```

- Takes `a_mag` to < 2
- By no means noise free
- accel + gyro if vibrations are at a dull roar. 
- When accelValid goes false often, you'll see major problems with drift
- ChatG says there are improved gating strategies (a hysteresis-based accel valid window, or a frequency-domain vibration rejection trick) which I did not try. 
- There's a product, moongel, place under the PCB and IMU

This also helped to follow the status of vibration reduction:

`./plot_amag.py -p /dev/cu.usbmodem178888901`

## Torque validation

Did not go too crazy with this so far. Used the MESC serial to show 
- the bot can lift itself up in
- both motors are roughly equal

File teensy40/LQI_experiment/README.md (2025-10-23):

# LQI ≡ Linear–Quadratic–Integral 

What I find interesting about Linear–Quadratic control methods (e.g., LQR and LQI) is they begin with the physical laws that govern the plant — equations originally formulated by Isaac Newton -- that express how forces, torques, and accelerations relate to system motion. These continuous-time dynamics are then forumulated into a state-space model, where matrix algebra captures how all relevant states (such as position, velocity, and integral error) will evolve under control inputs. 

From this model, an optimal feedback law is derived that minimizes a user-defined cost function, allowing the designer to tune intuitive weighting parameters (𝑄 and 𝑅) that balance performance against effort. The result is a compact set of gain values (𝐾𝜃, 𝐾𝜔, 𝐾𝑖) that are used as simple numerical coefficients that are deployed directly on the microcontroller. Remarkably this control law distills down to a simple line of code on the microcontroller:

```c
    torque_cmd = Kth_term * error - Kw_term * omega + Ki_term * integ_error;
```

These gains transform a complex physical model into efficient, real-time control.

## LQI Setup, Workflow

- Gather up motor constants Ke, Kt, Kv
- Plot motor decay constant
- Use those constants to develop LQI model
- Test LQI gains, plot motor behavior
- Run final set of gains on controller

## Calculate Motor Constants Ke, Kt, Kv

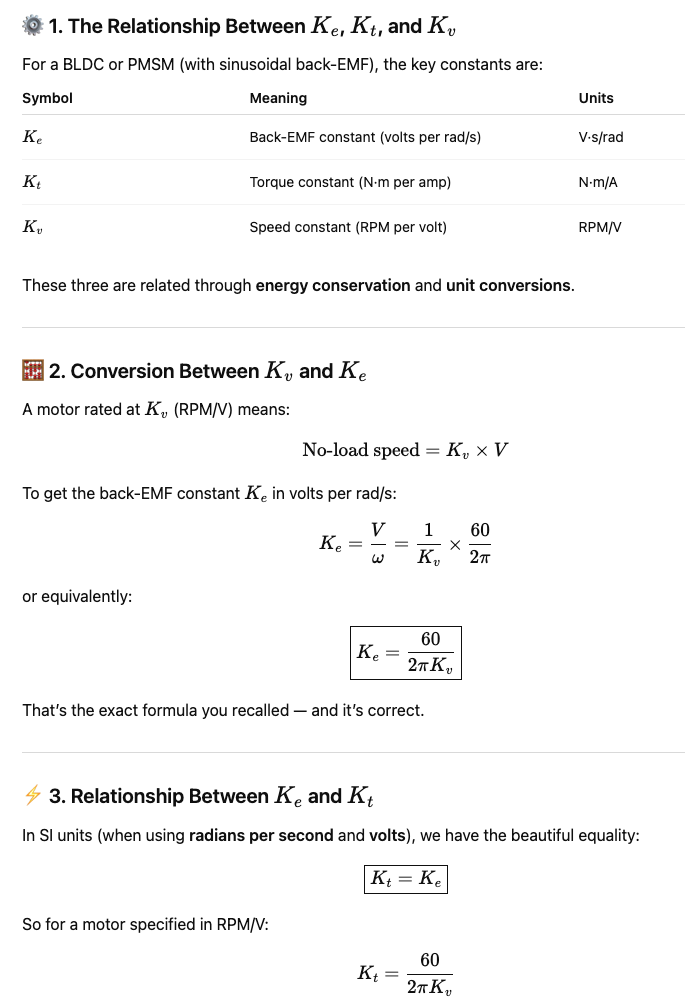
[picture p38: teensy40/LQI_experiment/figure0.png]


## Measure Motor Constant: decay

After applying a known torque pulse to the motor, the control program records the motor’s angular velocity as it freely spins down once the torque command is set to zero. During this free-decay phase, no active control or regenerative braking is applied—the motion is governed solely by passive damping effects such as bearing friction, air drag, and internal electrical losses.

The motor’s deceleration follows the first-order dynamic model:

𝐽𝜔˙ + 𝑏 = 0

whose analytical solution is:

𝜔(𝑡) = 𝜔0𝑒 <sup>−(𝑏/𝐽)𝑡</sup>

Taking the natural logarithm of velocity gives a linear relationship:

ln(𝜔) = ln(𝜔0) − 𝜆𝑡

where the slope 𝜆 = 𝑏 / 𝐽 is the decay constant.

The program automatically identifies the point where torque drops to zero and fits a straight line to the logarithm of the velocity data in the decay region. From this, it computes:

- Decay constant: 𝜆 = 𝑏 / 𝐽
- Damping coefficient: 𝑏 = 𝜆 𝐽 (if the inertia is known or estimated)

These values are displayed in the GUI label and provide a direct, repeatable way to quantify mechanical damping in the system. The estimated damping coefficient 𝑏 is used later in the control model to refine LQR/LQI design and improve accuracy in simulated or analytical predictions.

## Python Interface

Launch the graphing program

```
$ ./LQI_experiment.py -p /dev/cu.usbmodem178888901 -j pulse.json
```

json command passed to teensy:
``` {'cmd': 'send', 'pulse_torque': 0.4, 'total_us': 2000000, 'pulse_us': 500000}```

This spins the **bare** motor (no pendululum) and gives this result: 

<img src="Figure_1.png" alt="Plot result" width="300"/>

Estimated decay constant 
- `λ = 3.1526 s⁻¹` 
- `b = 3.15e-04`

## Modeling 

So now have a bunch of variables to complete the LQI modeling. Let's go:

<img src="Figure3.png" alt="Plot result" width="600"/>

Parameters used for tuning:

| Parameter             | Description                           | Typical Starting Point                                                      |
| --------------------- | ------------------------------------- | --------------------------------------------------------------------------- |
| (Q)                   | State weighting matrix                | [𝑄𝜃, 𝑄𝜔, 𝑄𝑖] — emphasize position & integral more than velocity       |
| (R)                   | Control effort weight                 | scalar; start around 0.1–10 depending on how aggressive you want torque use |
| sampling period (T_s) | Discretization step (for Teensy loop) | 1–2 ms (≈ 500–1000 Hz outer loop)                                           |
| actuator limits       | torque or current saturation          | ± Kₜ · Iₘₐₓ, e.g. ± 1.68 N·m for 30 A                                       |

Once 𝑄, 𝑅 are computed, this enables you to move variables on to the teensy for:  
**𝐾 = [𝐾𝜃, 𝐾𝜃˙,𝐾𝑖]**

## Tuning for Position Control

The inputs are passed as json on parameters, and will include:  
Kt = 0.005617 Nm, λ = 3.1526 s⁻¹ , b=3.15e-04 and Ts = 0.002

they will be passed in this way: 

```
{
  "qterm": "[.1, 10.0, .05]",
  "rterm": 200000.0,
  "Kt": 0.005617,
  "lambda": 3.1526,
  "Ts": 0.002,
  "b_decay": 0.000315,
  "torque": 1.0,
  "theta": 3.0,
  "total_ms": 1100,
  "LQI_path": "/Users/owhite/MESC_brain_board/teensy40/LQI_experiment"
}
```
These data are used by the python program:

```
$ ./LQI_command.py -p /dev/cu.usbmodem178888901 -j params.json
```

which outputs the data from the desktop to the teensy through the serial using the json:

```
{'cmd': 'position', 'torque': 1.0, 'total_us': 1100000, 'user_Kth_term': 0.0523, 'user_Kw_term': 0.0147, 'user_Ki_term': 0.0158, 'theta_ref': 3.0}
```

The teensy reads the K-gains and converts to torque commands here:

```c
void run_mode_set_position(Supervisor_typedef *sup,
                           FlexCAN_T4<CAN1, RX_SIZE_256, TX_SIZE_16> &can) {
    if (!sup->esc[0].state.alive) { return; }

    static bool first_entry = true;
    static unsigned long start_time = 0;

    // ---------------- Control parameters ----------------
    const float TORQUE_CLAMP = 0.6f;

    float torque       = (sup->user_torque != 0)   ? sup->user_torque   : 0.0f;
    float Kth_term     = (sup->user_Kth_term != 0) ? sup->user_Kth_term : 0.0f;
    float Kw_term      = (sup->user_Kw_term != 0)  ? sup->user_Kw_term  : 0.0f;
    float Ki_term      = (sup->user_Ki_term != 0)  ? sup->user_Ki_term  : 0.0f;
    uint32_t total_us  = (sup->user_total_us != 0) ? sup->user_total_us : 0;

    // ---------------- Initialize  ----------------
    if (first_entry) {
        logIndex = 0;
        first_entry = false;
        start_time = micros();

	Serial.printf("{\"cmd\":\"PRINT\",\"note\":\"%s\", \"torque\":%.3f, \"Kth\":%.3f, \"Kw\":%.3f, \"Ki\":%.3f, \"total_us\":%lu}\n", 
	      "LQI set position started",
		      torque,
		      Kth_term,
		      Kw_term,
		      Ki_term,
		      total_us
		      );

    }

    // Timing
    unsigned long now_time = micros();
    unsigned long elapsed  = now_time - start_time;

    // static variables preserve integral state across calls
    static float integ_error = 0.0f;
    float torque_cmd = 0.0f;

    // Get current feedback
    float theta = sup->esc[0].state.pos_rad;
    float omega = sup->esc[0].state.vel_rad_s;
    float theta_ref = sup->user_theta;   // radians position

    // Compute position error
    //   this controls the sign/direction of motor
    float error = theta_ref - theta;

    // Integrate error over time
    float dt = 0.002f; // 2 ms control period
    integ_error += error * dt;
    integ_error = constrain(integ_error, -0.1f, 0.1f);

    // Reduce the velocity damping term by an order of magnitude
    //   matching the true mechanical damping of the motor
    Kw_term *= 0.1f;

    // Control law
    torque_cmd = Kth_term * error - Kw_term * omega + Ki_term * integ_error;

    // Clamp to safe limits
    if (torque_cmd > TORQUE_CLAMP)  torque_cmd = TORQUE_CLAMP;
    if (torque_cmd < -TORQUE_CLAMP) torque_cmd = -TORQUE_CLAMP;

    // Total_us elapsed, shut off
    if (elapsed >= total_us) {
      torque_cmd = 0.0f;
    }

    // Send torque over CAN
    CAN_message_t msg;
    msg.id = canMakeExtId(CAN_ID_IQREQ, TEENSY_NODE_ID, sup->esc[0].config.node_id);
    msg.len = 8;
    msg.flags.extended = 1;
    canPackFloat(torque_cmd, msg.buf);
    canPackFloat(0.0f, msg.buf + 4);
    can.write(msg);

    // Log 
    if (logIndex < LOGLEN) {
      logBuffer[logIndex++] = {
	elapsed,
	torque_cmd,
	sup->esc[0].state.pos_rad,
	sup->esc[0].state.vel_rad_s
      };
    }

    // End condition, dump the json log
    if (elapsed >= total_us) {
      Serial.println("{ \"samples\":[");
      for (int i = 0; i < logIndex; i++) {
        Serial.printf("{\"t\":%lu,\"torque\":%.4f,\"pos\":%.4f,\"vel\":%.4f}%s\r\n",
                      logBuffer[i].t_us,
                      logBuffer[i].torque,
                      logBuffer[i].pos,
                      logBuffer[i].vel,
                      (i < logIndex - 1) ? "," : "");
      }
      Serial.println("]}\r\n");

      sup->mode = SUP_MODE_IDLE;
      first_entry = true;
    }

    sup->esc[0].state.alive = false;
}
```

## Tuning Parameter Summary

The UI for the python graphing progam enables user input for the Q matrix, the R term and other variables. Adjusting each term has these impacts:

| Parameter | Symbol | Effect on Behavior | What You’ll See |
| --- | ---- | --- | --- |
| **Position weight** | 𝑄𝜃 | Penalizes position error | Higher → faster response, more torque, can overshoot |
| **Velocity weight** | 𝑄𝜔 | Penalizes angular speed | Higher → smoother motion, less oscillation, slower response |
| **Integrator weight** | 𝑄𝑖  | Penalizes accumulated error | Higher → removes steady-state bias faster, but can cause bounce or overshoot |
| **Torque weight** | 𝑅  | Penalizes torque effort | Higher → gentle, slower motion; Lower → aggressive, fast, more power draw |

🟢 Increase 𝑄𝜃
- Controller fights harder to correct position.
- Quicker movement toward target.
- More torque, possibly overshoot or oscillation.
- Good for: precision pointing or small loads.
- Bad for: high inertia or torque saturation limits.

🟣 Increase 𝑄𝜔
- Penalizes velocity — adds damping.
- Reduces overshoot and bounce.
- Too high: motion becomes sluggish, stalls before setpoint.
- Good for: stability and smoothness.

🟠 Increase 𝑄𝑖
- Stronger correction for small residual errors.
- Improves accuracy; reduces steady-state offset.
- Too high: integral windup → small oscillations or “creep.”
- Good for: eliminating long-term bias in load torque.

🔵 Increase 𝑅
- Discourages large torque commands.
- Makes controller conservative and smooth.
- Too high: system becomes underpowered, never reaches setpoint.
- Good for: when you want to test safely or avoid current spikes.

🔴 Decrease 𝑅
- Controller becomes aggressive.
- Higher torque, faster rise time.
- Too low: possible overshoot or torque saturation.
- Good for: when you want more “authority” (stronger actuation).

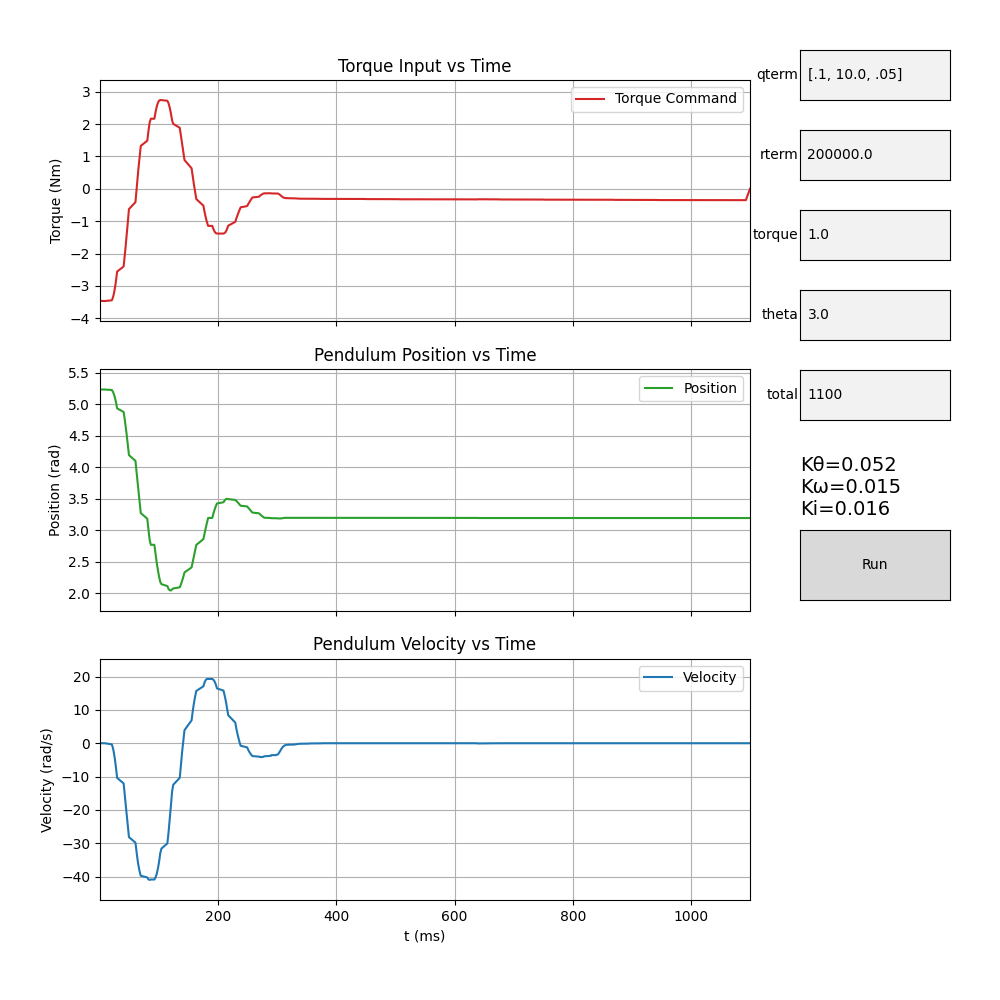
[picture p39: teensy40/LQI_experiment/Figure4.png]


**Note:** rapid settling time to position is 300ms. 

## Spinning the Motor Under LQI Control Law

**Sending position commands:** using the brain board's onboard RC transmitter. Fairly smooth results. 

LQI Tuning Result (https://www.youtube.com/watch?v=9YN7K3y4Kbw)

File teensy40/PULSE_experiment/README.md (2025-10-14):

# Torque Response Experiments & System Identification

This document describes the workflow for running **pulse torque experiments** on the Teensy + MESC setup and comparing results to a physics-based model (PyBullet or analytical). It builds directly on the ideas in `sept30_least_squares.md`.

---

## Goals

- Apply known torque inputs (pulses) to the pendulum/motor system.  
- Measure **position** and **velocity** response over time.  
- Compare experimental response to **model predictions**.  
- Use **least squares** fitting to refine system parameters (e.g., inertia, damping, Kt).  

---

## Motor Constants

We start from the motor’s published specs:

- Kv = **170 RPM/V** (from datasheet)  
- Relationship between Kv and torque constant Kt:

\[
K_t = \frac{60}{2 \pi \cdot K_v}
\]

- For Kv = 170:

\[
K_t \approx 0.056 \, \text{Nm/A}
\]

This constant does **not depend on supply voltage** (30 V in our case). Voltage only sets no-load speed.  

---

## From Torque (Nm) to ESC Command

1. **Desired Torque** \(T\): e.g., 0.2 Nm.  
2. **Required Current**:

\[
I = \frac{T}{K_t} = \frac{0.2}{0.056} \approx 3.57 \, \text{A}
\]

3. **Normalized Command**:  
   The ESC torque command ranges from -1.0 to +1.0, where 1.0 corresponds to ±I_max.  
   If I_max = 30 A:

\[
\text{command} = \frac{I}{I_\text{max}} = \frac{3.57}{30} \approx 0.12
\]

✅ So a **command ≈ 0.12** corresponds to ~0.2 Nm torque.

---

## Teensy Supervisor Integration

We extended the **Supervisor_typedef** to hold user-configurable pulse parameters:

```cpp
float    user_pulse_torque   = 0.2f;    // normalized command [-1,1]
uint32_t user_pulse_us       = 85000;   // pulse duration (µs)
uint32_t user_total_us       = 170000;  // total duration (µs)
```

---

## Torque Response Mode

We replaced the old `run_mode_set_position()` with:

```cpp
void run_mode_torque_response(Supervisor_typedef *sup,
                              FlexCAN_T4<CAN1, RX_SIZE_256, TX_SIZE_16> &can);
```

Behavior:

1. On entry:
   - Reset timer and log buffer.  
2. For first `user_pulse_us` µs:
   - Send `user_pulse_torque` as normalized torque command over CAN.  
3. For remainder up to `user_total_us` µs:
   - Send `0.0f` torque command.  
4. At `user_total_us`:
   - Dump collected samples in JSON:
     ```json
     { "samples": [
       {"t":0, "torque":0.2, "pos":..., "vel":...},
       {"t":1000, "torque":0.2, "pos":..., "vel":...},
       ...
     ]}
     ```
   - Exit to `SUP_MODE_IDLE`.  

---

## Logging

Each sample records:

- `t_us` (µs since start of experiment)  
- `torque` (normalized ESC command)  
- `pos` (measured rotor angle, rad)  
- `vel` (measured rotor velocity, rad/s)  

These logs are consumed later in Python for least squares fitting.

---

## Python Interface

We will use a Python + matplotlib GUI to:

1. Accept user parameters:
   - `Kt` (Nm/A)  
   - `pulse_duration` (ms)  
   - `torque_request` (Nm)  
2. Compute:
   - Phase current: \(I = T / K_t\)  
   - Normalized command: \(I / I_\text{max}\)  
3. Send configuration (`user_pulse_torque`, `user_pulse_us`, `user_total_us`) to the Teensy over serial.  
4. Run the experiment.  
5. Retrieve JSON logs and overlay experimental response with PyBullet predictions.  

Launch the graphing program
```
$ ./torque_raise.py  /dev/cu.usbmodem178888901
```

---

## Modeling & Validation

- In PyBullet (or analytical model), simulate the pendulum response to the same pulse torque input.  
- Compare **position** and **velocity** traces to experimental data.  
- Apply **least squares fitting** to minimize error and update estimated parameters (inertia, damping, Kt).  
- Iterate until model matches physical system.  

---

## Estimate the 𝐵 term of the physical plant from real data

The standard state-space model for a pendulum is 𝑥-dot =Ax+𝐵u, where 𝐵 represents how strongly the applied control input u (torque) affects the pendulum’s angular acceleration. To model 𝐵 accurately, we need to determine how much actual physical torque the motor produces for a given commanded torque value from the controller. In other words, we must measure the motor’s torque-per-command ratio — the mapping between the controller’s normalized input and the true torque applied at the pendulum joint.

- Run: `$ ./torque_raise.py /dev/cu.usbmodem178888901`
- The program computes acceleration: `np.gradient(vel, t)` numerically differentiates velocity.
- Estimated `𝐵_real` = 102.5 rad/s² per N·m
- The results are:

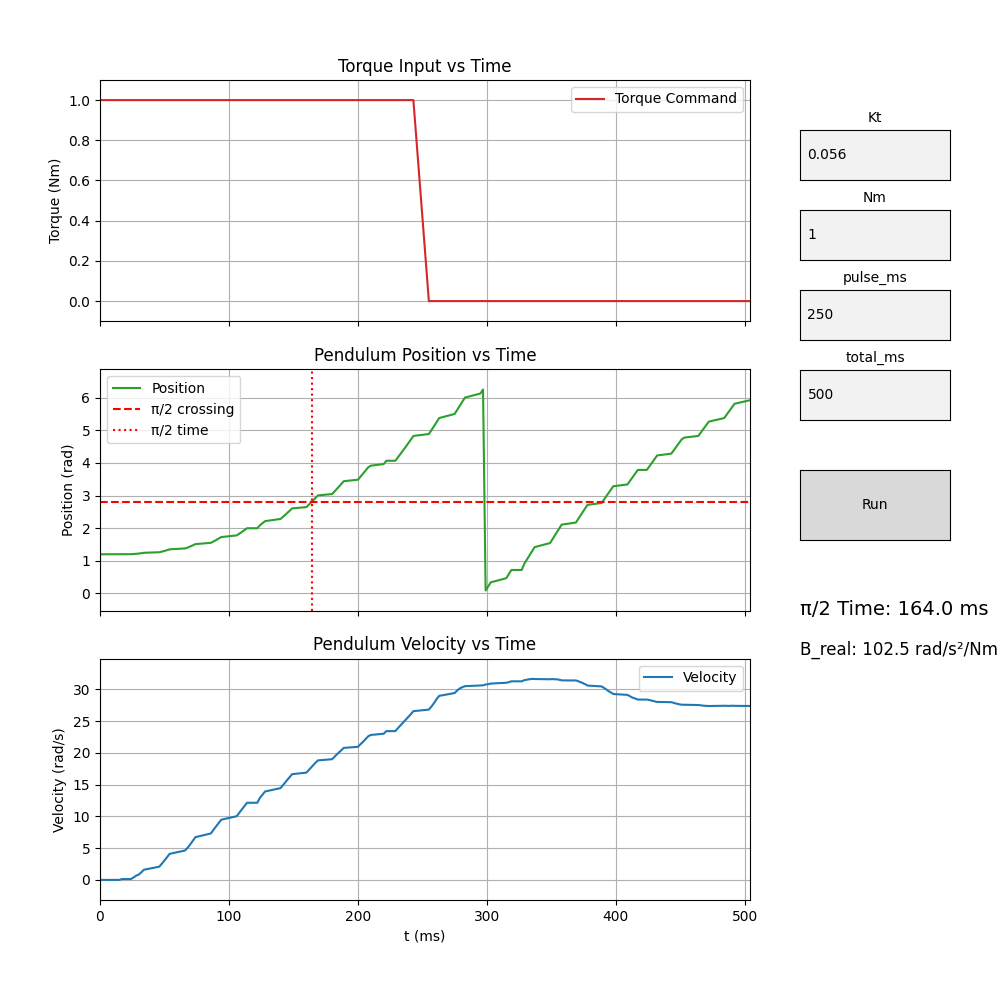
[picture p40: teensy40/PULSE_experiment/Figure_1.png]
Plot result


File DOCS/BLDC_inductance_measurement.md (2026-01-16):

# Measuring Phase, d-axis, and q-axis Inductance of a BLDC Motor
*(Step-response method with bench supply and oscilloscope)*

## Goal
Measure the **phase-to-phase inductance** of a BLDC motor using a current step response, then extract **Ld** and **Lq** by repeating the measurement versus rotor angle.

This procedure was applied to a **GBM5208-200T (12N14P, wye)** motor and produced time constants ranging from **600 µs to 1000 µs** depending on rotor position.

---

## Required hardware
- BLDC motor (three leads)
- Bench power supply (5 V used here)
- Series resistor: **1 Ω, ≥10 W**
- Manual switch 
- Oscilloscope with single-shot capture
- Test leads

---

## Physical setup

### Wiring
1. Choose two motor phases (A and B). Leave the third phase floating.
2. Wire in series:

   **Supply + → switch → 1 Ω resistor → phase A → phase B → supply −**

This forms a simple series **R–L** circuit.

### Oscilloscope
3. Connect the scope probe **across the 1 Ω resistor**.
   - This voltage directly represents current:
     - **1 V = 1 A**

(Optional: second channel across the motor terminals.)

---

## Electrical preparation

### Measure resistance
4. Measure phase-to-phase DC resistance with a DMM (rotor stationary).

Example (GBM5208-200T):
- Phase-to-phase resistance: **≈17 Ω**
- Series resistor: **1 Ω**

5. Compute total resistance:
```
R_total ≈ 17 Ω + 1 Ω = 18 Ω
```

### Choose supply voltage
6. Use a low voltage to limit current and torque.
   - **5 V** was used

Expected steady current:
```
I = V / R_total ≈ 5 / 18 ≈ 0.28 A
```

Expected scope plateau:
```
V_shunt ≈ 0.28 V
```

---

## Capturing the step response

7. Configure the scope:
   - Single-shot mode
   - Trigger on rising edge of shunt voltage
   - Timebase so the rise is clearly visible (hundreds of µs/div)

8. Close the switch to apply the voltage step.

You should see an exponential rise in the shunt voltage.

---

## Extracting inductance

### Use the 63.2% time-constant method
9. Measure the final shunt voltage plateau \(V_final\).

10. Compute the 63.2% level:
```
V_63 = 0.632 × V_final
```

11. Measure the time from the step start to when the trace crosses \(V_63\).
    This time is the RL time constant **τ**.

- Put tape on 60 degrees of the motor
- Mark ~8 spots
- Putting 1V on the motor makes it jump, so clamp to the table to hold position
- Take 8 measurements

12. Compute phase-to-phase inductance:
```
L_pp = τ × R_total
```
use min and max values from the 8 measurements

---

## Measuring Ld and Lq (saliency)

The motor is **12N14P**:
- 14 poles → **7 pole pairs**
- Inductance varies with rotor angle

### Practical method
13. Repeat the step-response measurement while holding the rotor at different positions.
14. Record the minimum and maximum time constants observed.

For the **GBM5208-200T**:
- τ_min ≈ **600 µs**
- τ_max ≈ **1000 µs**

15. Compute phase-to-phase inductances:
```
L_d,pp ≈ τ_min × R_total ≈ 600 µs × 18 Ω ≈ 10.8 mH
L_q,pp ≈ τ_max × R_total ≈ 1000 µs × 18 Ω ≈ 18.0 mH
```

Assign:
- **Ld ≈ minimum inductance**
- **Lq ≈ maximum inductance**

---

## Convert to per-phase inductance (wye connection)

For a symmetric wye motor:
```
L_phase ≈ L_pp / 2
```

So:
```
Ld ≈ 10.8 mH / 2 ≈ 5.4 mH
Lq ≈ 18.0 mH / 2 ≈ 9.0 mH
```

Saliency ratio:
```
Lq / Ld ≈ 1.67
```

---

## Notes for repeatability
- Keep voltage low to avoid rotor motion and heating.
- Ignore initial switching noise; use the exponential envelope.
- Use short leads and, if needed, limit scope bandwidth (~20 MHz).
- Report inductance as a range if rotor angle is uncontrolled.

---

# Measuring Phase, d-axis, and q-axis Inductance of a BLDC Motor
*(Step-response method with bench supply and oscilloscope)*

## Goal
Measure the **phase-to-phase inductance** of a BLDC motor using a current step response, then extract **Ld** and **Lq** by repeating the measurement versus rotor angle.

This procedure was applied to a **GBM5208-200T (12N14P, wye)** motor and produced time constants ranging from **600 µs to 1000 µs** depending on rotor position.

---

## Required hardware
- BLDC motor (three leads)
- Bench power supply (5 V used here)
- Series resistor: **1 Ω, ≥10 W**
- Manual switch 
- Oscilloscope with single-shot capture
- Test leads

---

## Physical setup

### Wiring
1. Choose two motor phases (A and B). Leave the third phase floating.
2. Wire in series:

   **Supply + → switch → 1 Ω resistor → phase A → phase B → supply −**

This forms a simple series **R–L** circuit.

### Oscilloscope
3. Connect the scope probe **across the 1 Ω resistor**.
   - This voltage directly represents current:
     - **1 V = 1 A**

(Optional: second channel across the motor terminals.)

---

## Electrical preparation

### Measure resistance
4. Measure phase-to-phase DC resistance with a DMM (rotor stationary).

Example (GBM5208-200T):
- Phase-to-phase resistance: **≈17 Ω**
- Series resistor: **1 Ω**

5. Compute total resistance:
```
R_total ≈ 17 Ω + 1 Ω = 18 Ω
```

### Choose supply voltage
6. Use a low voltage to limit current and torque.
   - **5 V** was used

Expected steady current:
```
I = V / R_total ≈ 5 / 18 ≈ 0.28 A
```

Expected scope plateau:
```
V_shunt ≈ 0.28 V
```

---

## Capturing the step response

7. Configure the scope:
   - Single-shot mode
   - Trigger on rising edge of shunt voltage
   - Timebase so the rise is clearly visible (hundreds of µs/div)

8. Close the switch to apply the voltage step.

You should see an exponential rise in the shunt voltage.

---

## Extracting inductance

### Use the 63.2% time-constant method
9. Measure the final shunt voltage plateau \(V_final\).

10. Compute the 63.2% level:
```
V_63 = 0.632 × V_final
```

11. Measure the time from the step start to when the trace crosses \(V_63\).
    This time is the RL time constant **τ**.

- Put tape on 60 degrees of the motor
- Mark ~8 spots
- Putting 1V on the motor makes it jump, so clamp to the table to hold position
- Take 8 measurements

12. Compute phase-to-phase inductance:
```
L_pp = τ × R_total
```
use min and max values from the 8 measurements

---

## Measuring Ld and Lq (saliency)

The motor is **12N14P**:
- 14 poles → **7 pole pairs**
- Inductance varies with rotor angle

### Practical method
13. Repeat the step-response measurement while holding the rotor at different positions.
14. Record the minimum and maximum time constants observed.

For the **GBM5208-200T**:
- τ_min ≈ **600 µs**
- τ_max ≈ **1000 µs**

15. Compute phase-to-phase inductances:
```
L_d,pp ≈ τ_min × R_total ≈ 600 µs × 18 Ω ≈ 10.8 mH
L_q,pp ≈ τ_max × R_total ≈ 1000 µs × 18 Ω ≈ 18.0 mH
```

Assign:
- **Ld ≈ minimum inductance**
- **Lq ≈ maximum inductance**

---

## Convert to per-phase inductance (wye connection)

For a symmetric wye motor:
```
L_phase ≈ L_pp / 2
```

So:
```
Ld ≈ 10.8 mH / 2 ≈ 5.4 mH
Lq ≈ 18.0 mH / 2 ≈ 9.0 mH
```

Saliency ratio:
```
Lq / Ld ≈ 1.67
```

---

## Notes for repeatability
- Keep voltage low to avoid rotor motion and heating.
- Ignore initial switching noise; use the exponential envelope.
- Use short leads and, if needed, limit scope bandwidth (~20 MHz).
- Report inductance as a range if rotor angle is uncontrolled.

## Prompt with chatgpt
Walk me through measuring BLDC motor phase resistance and inductance using simple bench equipment.

## Available equipment: ##
- Isolated, adjustable bench DC power supply (voltage & current limit)
- 1 Ω, 10 W resistor
- Earth-grounded Oscilloscope (≥2 channels)
- Multimeter
- BLDC motor (three-phase, disconnected from any controller)

## Connections: ##
PSU+ → Motor lead A → Motor lead B → switch → 1 Ω resistor → PSU−

## Goals: ##
- Measure per-phase resistance (Ω).
- Measure per-phase inductance (H).
- Sanity-check the results against motor physics and expected KV / torque constant.

## Constraints & style: ##
- We will not use an LCR meter
- Use step-response and RL time-constant methods, not impedance analyzers.
- Be explicit about wye vs delta assumptions and conversions.
- Ask me to confirm scope probe placement and safety limits before applying power.
- Keep units consistent and report final inductance in henries (not mH).

## Before beginning  ##
- Ask me for my best guess of the motor’s key specs:
- Approximate KV (rpm/V)
- Expected phase-to-phase resistance range
- Expected inductance range
- Intended application (e.g., balancing robot, gimbal, scooter, etc.)
- Ask what supply voltage and current limit I plan to start with.

## Measurement approach ##
- First: DC resistance measurement using the resistor as a current sense element.
- Second: Inductance measurement using a voltage step, capturing the current rise on the oscilloscope, extracting τ = L/R, and solving for L.
- Explain each step briefly, then wait for my measured values before continuing.

## Behavior: ##
- Do not skip steps.
- Do not assume ideal components.
- Question results that look physically inconsistent.
- Treat this like a real bench experiment, not a textbook problem.

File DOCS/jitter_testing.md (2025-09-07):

## Measuring fastLoop() Timing Jitter

### 1. Generating a Test Signal on the STM32F405 (MESC)

I added these functions to MESC code:

```c
// PB5 setup
static inline void jitter_pin_init(void) {
  RCC->AHB1ENR |= RCC_AHB1ENR_GPIOBEN; (void)RCC->AHB1ENR;

  GPIOB->MODER   = (GPIOB->MODER & ~(3U << (5U*2))) | (1U << (5U*2));
  GPIOB->OTYPER &= ~(1U << 5);
  GPIOB->OSPEEDR |= (3U << (5U*2));
  GPIOB->PUPDR &= ~(3U << (5U*2));
  GPIOB->BSRR = (1U << 5) << 16;
}

static inline void jit_set(void)    { GPIOB->BSRR =  (1U << 5); }
static inline void jit_clr(void)    { GPIOB->BSRR = ((1U << 5) << 16); }
static inline void jit_toggle(void) {  GPIOB->ODR ^= (1U << 5); }

```

Then with MESC_Firmware/MESC_Common/Src/MESCfoc.c

add this into the end of **fastLoop()**

```c
static inline void jit_toggle(void) {  GPIOB->ODR ^= (1U << 5); }
```

Put a scope on PB5 and get this:

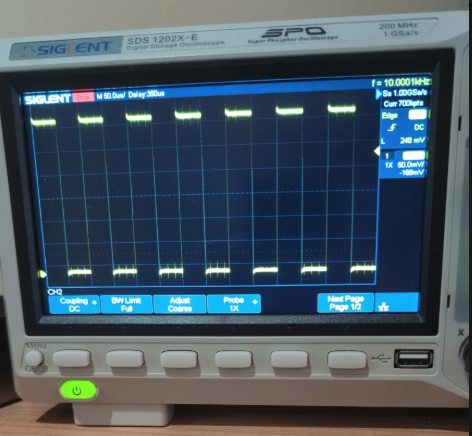
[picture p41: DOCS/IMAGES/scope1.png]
Block diagram


### Result:
- **Each toggle = one call to `fastLoop()`**, so:
  - Square wave frequency = half the loop frequency.
- Example: observing ~10 kHz on oscilloscope → means `fastLoop()` executes at ~20 kHz.

---

### 2. Measure the output with the Teensy 4.0
- Connected ESC test pin → **Teensy pin 9** (interrupt-capable).
- On the brain board this is the PWM in header for reading an RC transmitter
- Teensy runs an **ISR on rising edges**:
  - Timestamps each edge with the **ARM cycle counter** (`ARM_DWT_CYCCNT`).
  - Stores timestamps into a **ring buffer** (ISR-safe).
- Main loop:
  - Computes **period (µs)** = time difference between edges.
  - Computes **jitter/error (µs)** = deviation from target period.
  - Outputs NDJSON over USB serial, e.g.:
    ```json
    {"seq":1234,"t_us":1234567.890,"period_us":50.0,"target_us":50.0,"err_us":0.05}
    ```

---

### 3. Host PC Logging & Plotting
- Python script reads Teensy’s serial NDJSON stream.
- Parses JSON lines and stores into rolling buffers.
- Plots in real-time using Matplotlib:
  - **Period vs. sample**
  - **Jitter vs. sample**
  - **Jitter histogram** (distribution shape)
  - **Jitter violin plot** (spread + density)

Run script:
```
python3 ./plot_teensy_jitter.py /dev/cu.usbmodem178888901
```

Typical result showing there is a very small amount of fastLoop() delays:

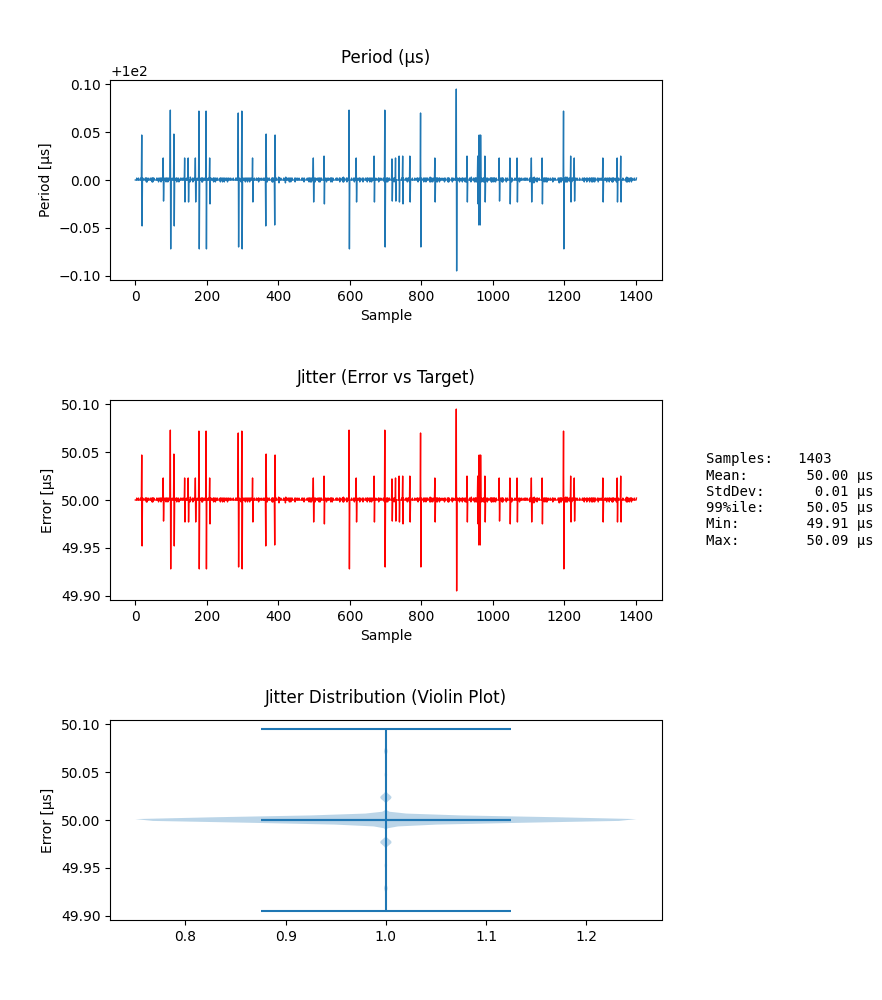
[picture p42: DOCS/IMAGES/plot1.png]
Plot result


This example shows virtually no change after increasing CAN messages to 500kz:

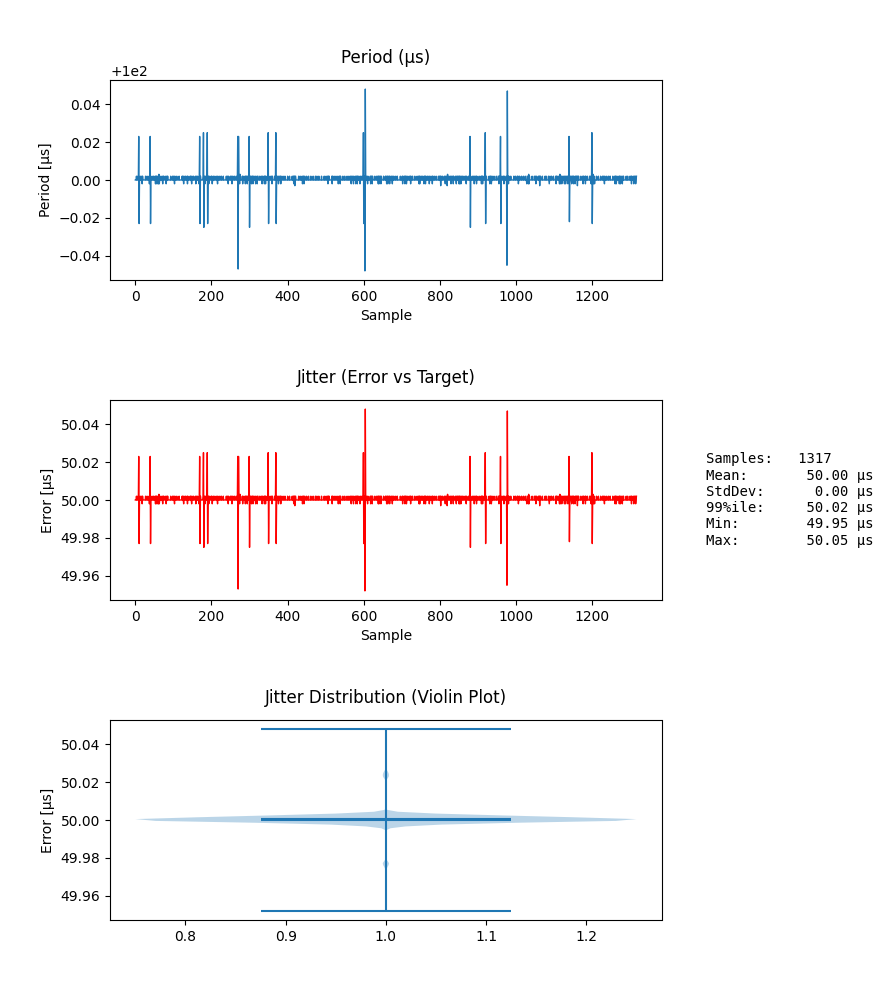
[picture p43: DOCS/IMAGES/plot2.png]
Plot result


### Outcome
- Jitter measured in **sub-µs range**, with only rare small spikes.
- Demonstrates loop timing is stable enough for deterministic FOC.
- Workflow (ESC pin toggle → Teensy capture → Python plots) provides a **portable jitter analyzer** for real-time firmware validation.
- This will be useful to test if other changes to MESC code have a negative impact
- CAN running at 500hz doesnt seemt to impact anything

---
### 4. Internal Jitter Measurement on the STM32F405 (DWT + 10 Hz CAN Telemetry)

In addition to the external pin toggle + Teensy capture, we will also measure jitter directly inside the STM32F405 using the Cortex-M4 DWT cycle counter. We’ll aggregate min/max/average error over ~100 ms and export a small CAN telemetry frame at 10 Hz so the Teensy/PC can monitor loop health.

**4.1 Create a new struct in MESCfoc.h** 

```c
#ifdef POSVEL_PLANE
// Jitter metrics for fastLoop() entry-to-entry period, measured via DWT->CYCCNT
typedef struct {
    int32_t  min_cyc, max_cyc;
    int64_t  sum_cyc;
    uint32_t samples;
    uint32_t last_entry_cyc;
    int32_t  expected_cyc;
    float    avg_us; // average jitter over all samples, in microseconds
    float    p2p_us; // peak-to-peak jitter over all samples, in microseconds
    volatile uint8_t clear_req;
} MESCjitter_s;
#endif
```

and add this to the big motor typedef:

```c
typedef struct{
	TIM_HandleTypeDef *mtimer; //3 phase PWM timer
.
.
.
	input_vars_t input_vars;
	MESClrobs_s lrobs;
	MESCoptionFlags_s options;
	bool conf_is_valid;
#ifdef POSVEL_PLANE
    MESCjitter_s jitter;     // fastLoop() timing jitter metrics
#endif
}MESC_motor_typedef;
```

**4.2 Measure timing at the top of fastLoop()**

```c
void fastLoop(MESC_motor_typedef *_motor) {
	uint32_t cycles = CPU_CYCLES;

#ifdef JITTER_TEST
	//
	// god forgive the idiot that puts something at the top of fastLoop()
	//
	uint32_t period = cycles - _motor->jitter.last_entry_cyc;   // wrap-safe
	_motor->jitter.last_entry_cyc = cycles;

	if (period != 0u) { // skip first sample
	    int32_t jitter_cyc = (int32_t)period - _motor->jitter.expected_cyc;

	    if (jitter_cyc < _motor->jitter.min_cyc) _motor->jitter.min_cyc = jitter_cyc;
	    if (jitter_cyc > _motor->jitter.max_cyc) _motor->jitter.max_cyc = jitter_cyc;
	    _motor->jitter.sum_cyc += jitter_cyc;
	    _motor->jitter.samples++;
	}

	// Resets after request from the task
	if (_motor->jitter.clear_req) {
	    _motor->jitter.min_cyc = INT32_MAX;
	    _motor->jitter.max_cyc = INT32_MIN;
	    _motor->jitter.sum_cyc = 0;
	    _motor->jitter.samples = 0;
	    _motor->jitter.clear_req = 0;
	}

#endif
```
**4.3 Define a telemetry CAN ID**
```c
// can_ids.h
#define CAN_ID_JITTER  0x350  // pick any unused base ID in your scheme
```

**4.4 Send a compact 8-byte CAN frame using the current helper**
- Payload layout (8 bytes total):
- bytes 0–3: float jitter.avg_us
- bytes 4–7: float jitter.p2p_us

```c
void TASK_CAN_telemetry_fast(TASK_CAN_handle * handle){

	MESC_motor_typedef * motor_curr = &mtr[0];

	TASK_CAN_add_float(handle	, CAN_ID_ADC1_2_REQ	  	, CAN_BROADCAST, motor_curr->input_vars.ADC1_req		, motor_curr->input_vars.ADC2_req	, 0);
	TASK_CAN_add_float(handle	, CAN_ID_SPEED		  	, CAN_BROADCAST, motor_curr->FOC.eHz		, 0.0f					, 0);
	TASK_CAN_add_float(handle	, CAN_ID_BUS_VOLT_CURR 	, CAN_BROADCAST, motor_curr->Conv.Vbus		, motor_curr->FOC.Ibus	, 0);
	TASK_CAN_add_uint32(handle	, CAN_ID_STATUS	  		, CAN_BROADCAST, motor_curr->MotorState		, 0						, 0);
	TASK_CAN_add_float(handle	, CAN_ID_MOTOR_CURRENT 	, CAN_BROADCAST, motor_curr->FOC.Idq.q		, motor_curr->FOC.Idq.d	, 0);
	TASK_CAN_add_float(handle	, CAN_ID_MOTOR_VOLTAGE 	, CAN_BROADCAST, motor_curr->FOC.Vdq.q		, motor_curr->FOC.Vdq.d	, 0);

#ifdef POSVEL_PLANE
	// these values are somewhat untested in that I've
	//  never been able to make fastLoop() slow down
	uint32_t n       = motor_curr->jitter.samples;
    int32_t  min_cyc = motor_curr->jitter.min_cyc;
    int32_t  max_cyc = motor_curr->jitter.max_cyc;
    int64_t  sum_cyc = motor_curr->jitter.sum_cyc;

    if (n > 0 && min_cyc != INT32_MAX && max_cyc != INT32_MIN) {
        const float cyc2us = 1.0f / ((float)SystemCoreClock / 1e6f);
        motor_curr->jitter.avg_us = ((float)sum_cyc / (float)n) * cyc2us;
        motor_curr->jitter.p2p_us = (float)(max_cyc - min_cyc) * cyc2us;

        TASK_CAN_add_float(handle, CAN_ID_JITTER, CAN_BROADCAST, motor_curr->jitter.avg_us, motor_curr->jitter.p2p_us, 0);

        motor_curr->jitter.clear_req = 1; // ask ISR to reset window
    }
#endif

}

Print or plot these alongside other telemetry to confirm that added bus traffic or firmware changes do not degrade control-loop determinism.

**Notes & Tips**
- If your fastLoop() frequency isn’t 20 kHz, just set EXPECTED_HZ accordingly.
- DWT->CYCCNT wraps every ~25.5 s at 168 MHz; because we take differences each call, wrap is safe.
- For even more context you can add a sequence counter to this frame so the Teensy can detect any lost jitter packets.

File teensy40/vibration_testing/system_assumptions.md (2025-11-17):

# System Assumptions and Tests for Two-Wheeled Balancing Robot (TWR)

This document lists the **implicit assumptions** your balancing robot system relies on, along with **tests** you can perform to verify each one. These assumptions span sensors, kinematics, dynamics, actuation, filtering, timing, and modeling.

---

## 1. Geometry & Kinematics Assumptions

### **A1. IMU tilt = body tilt**
**Assumption:** IMU pitch matches true robot pitch.  
**Test:** Tilt robot on a measured board (5°, 10°, 15°) and confirm logged pitch matches.

### **A2. Wheel angle ↔ linear displacement**
**Assumption:** `x_wheel = radius × wheel_angle` matches real displacement.  
**Test:** Move robot along marked distances; compare encoder-based estimate.

### **A3. Unwrapping is correct**
**Assumption:** Wheel angles don’t jump at ±π.  
**Test:** Spin wheel by hand through multiple revolutions and plot `x_wheel`.

### **A4. COM and inertia match model**
**Assumption:** Physical COM and I_body are close to modeled values.  
**Test:** Measure small oscillation frequency or verify static torque-angle relationship.

---

## 2. Sensor Assumptions

### **S1. IMU rate = actual angular rate**
**Assumption:** `pitch_rate` matches physical angular velocity.  
**Test:** High-frame-rate video comparison.

### **S2. Correct gyro axis for pitch**
**Assumption:** The selected gyro axis truly corresponds to pitch.  
**Test:** Rotate robot around each axis; check which gyro axis responds.

### **S3. Wheel velocity reading is accurate**
**Assumption:** `vel_rad_s` reflects true wheel speed.  
**Test:** Compare measured time per revolution with logged velocity.

### **S4. Latency is small/constant**
**Assumption:** Loop delay IMU → control → torque is small.  
**Test:** Send step torque, observe IMU acceleration start time.

---

## 3. Actuation / ESC Assumptions

### **E1. Torque command ∝ actual torque**
**Assumption:** Sent torque produces proportional torque at wheel.  
**Test:** Use spring scale or lever arm to measure torque.

### **E2. Torque direction matches model**
**Assumption:** +u makes robot tilt in expected way.  
**Test:** Command small u and observe initial tilt direction.

### **E3. Motors behave symmetrically**
**Assumption:** Left/right torque for same u are similar.  
**Test:** Free-spin both with same torque; compare velocities.

### **E4. No large torque deadzone**
**Assumption:** Small non-zero u produces motion/torque.  
**Test:** Slowly ramp u from 0 → upward and check first movement.

---

## 4. Timing / Loop Assumptions

### **T1. Loop runs at 500 Hz**
**Assumption:** `CONTROL_PERIOD_US` matches actual dt.  
**Test:** Log `dt_us` and inspect mean & variance.

### **T2. Mahony dt is correct**
**Assumption:** dt passed to Mahony matches actual IMU interrupt spacing.  
**Test:** Log `(now - last_update)` each time IMU updates.

---

## 5. Model / LQR Assumptions

### **M1. Linearization is valid**
**Assumption:** Small-angle dynamics approximate model.  
**Test:** With motors off, gently perturb robot in a rig and compare oscillation characteristics.

### **M2. Q and R reflect your priorities**
**Assumption:** Weighting properly emphasizes angle over position.  
**Test:** Simulate model-based step response and compare with desired behavior.

---

## 6. Coordinate Frame & Sign Conventions

### **C1. Pitch sign matches model**
**Assumption:** Positive tilt matches direction used in LQR model.  
**Test:** Tilt robot forward/back and confirm sign.

### **C2. Wheel motion corrects tilt**
**Assumption:** Forward wheel motion stabilizes a forward-leaning body.  
**Test:** Suspend robot, apply small forward torque, observe body response.

---

## 7. Noise & Filtering Assumptions

### **N1. Filters introduce acceptable lag**
**Assumption:** LPFs on θ̇ and ẋ don’t add excessive phase delay.  
**Test:** Compare raw vs filtered during slow oscillations.

### **N2. Noise is bounded/stationary**
**Assumption:** Motor vibration doesn’t explode noise magnitude.  
**Test:** Log RMS noise under various torque conditions.

---

## 8. Safety & Saturation Assumptions

### **S1. Torque limits are respected**
**Assumption:** `TORQUE_CLAMP` prevents saturation.  
**Test:** Log u + observe ESC current draw.

### **S2. Sufficient wheel traction**
**Assumption:** Wheels don’t slip under normal control forces.  
**Test:** High-torque tests on actual surface.

---

## Summary Table

| Category | Assumption | What You Expect | How to Test |
|---|---|---|---|
| Geometry | A1 | IMU pitch = real pitch | Measured tilt board |
| Geometry | A2 | Wheel angle → displacement | Tape measure test |
| Sensors | S1 | IMU rate = angular rate | Phone video |
| Actuation | E1 | u → linear torque | Spring scale |
| Control | T1 | 500 Hz loop | Log `dt_us` |
| Model | M1 | Linearization valid | Rig-based oscillation test |

---

This list is meant to be actionable: each assumption has a corresponding test.  
Validating these reduces uncertainty and makes successful balancing almost inevitable.

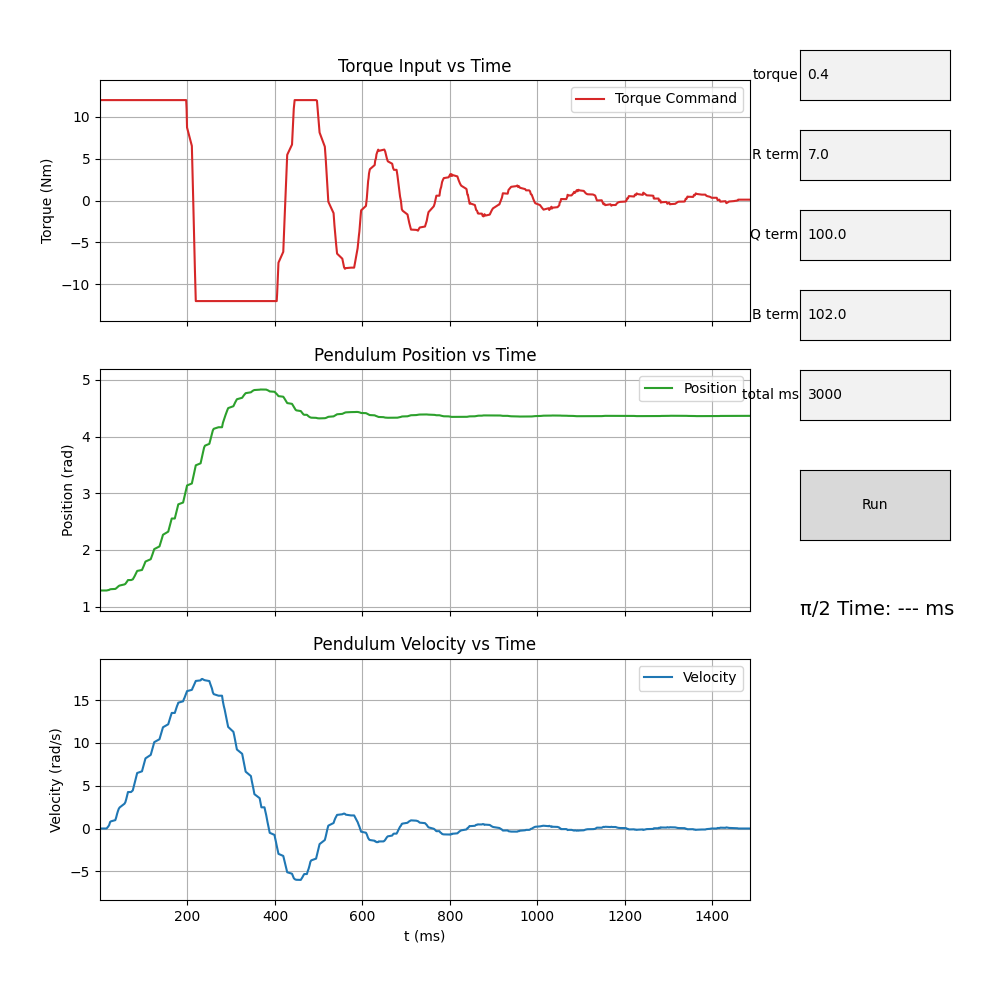
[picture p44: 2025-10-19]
teensy40/LQR_experiment/Figure1.png

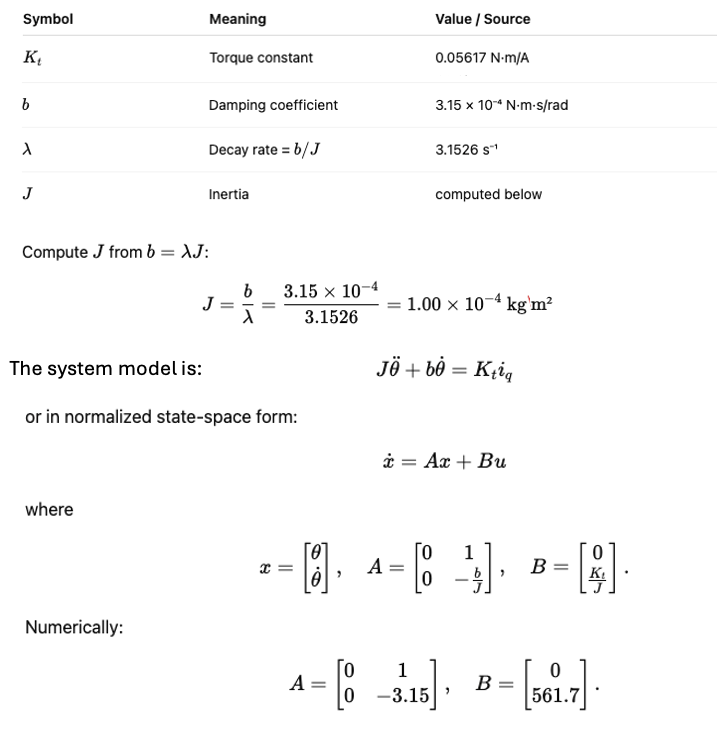
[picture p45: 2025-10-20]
teensy40/LQI_experiment/Figure3.png

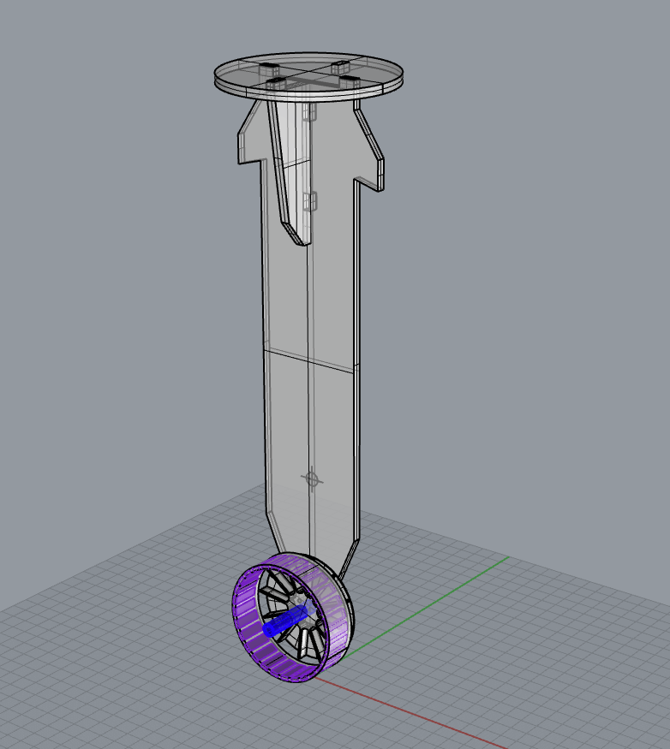
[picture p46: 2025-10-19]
teensy40/LQR_experiment/Figure2.png

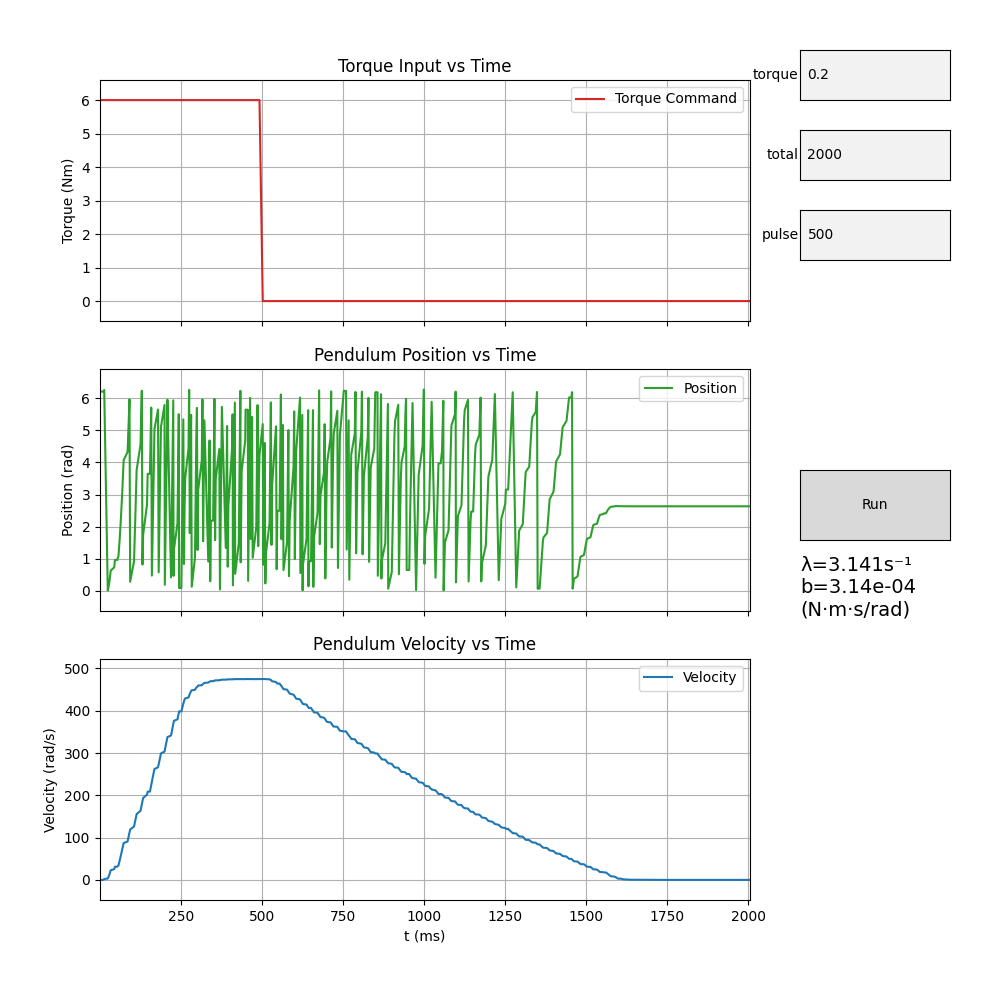
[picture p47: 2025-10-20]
teensy40/LQI_experiment/Figure_1.png

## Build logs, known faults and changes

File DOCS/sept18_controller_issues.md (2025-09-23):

## Sept 18, 2025
# Motor Controller System Issues Summary
Or, a list of things that can go wrong and must be ruled out. 

## 1. Torque Request → Phase Current Mapping
- Torque command may not map cleanly to actual **Iq current**, and therefore not to torque.  
- Causes: ESC nonlinearities, sensor noise, uncalibrated Kt, firmware cutoffs.  
- Result: unpredictable motor response, PID “chasing a moving target.”

---

## 2. Non-First-Order Plant (Wheel + Body)
- A motor alone looks roughly like a first-order system (current → torque → acceleration).  
- Once attached to a wheel and body:
  - The system becomes **at least second-order** (inertia + acceleration dynamics).  
  - If balancing (like a robot), it also includes **unstable poles**.  
- PID is designed for first-order plants → it won’t naturally stabilize this higher-order, unstable system.

---

## 3. Classic PID Limitations
- PID assumes proportional output to input, but your plant has:
  - Delays, inertia, and multiple energy storage elements.  
  - Nonlinear torque ↔ current mapping at low speeds.  
- This mismatch explains why endless PID tuning never yields stability.  

---

## 4. Missing Feedforward
- Without feedforward, PID has to do all the work reactively.  
- A feedforward torque term (e.g. to cancel gravity, rolling resistance, or expected acceleration) reduces error before feedback kicks in.  
- Advanced controllers like **moteus** rely heavily on feedforward for stability.

---

## 5. Second-Order Behavior
- Second order dynamics:  
  ```
  θ¨ = (1/J) * (τ - τdisturbance)
  ```
- Properties:  
  - Overshoot, ringing, and instability if damping is insufficient.  
  - PID can only add limited damping, and poorly if torque mapping is wrong.  
- Without explicit handling of second-order effects, the system oscillates instead of settling.

---

## 6. Other Likely Factors
- **Sensor limits**: encoder resolution, IMU noise → unstable estimates.  
- **Back-EMF & voltage saturation**: at higher speeds → torque per amp falls.  
- **Friction/cogging**: at low speed → deadzone effects that PID can’t handle smoothly.  
- **Task split**: if inner current loop isn’t fast enough, outer loop commands don’t track.

---

## ✅ One-Sentence Summary
Your system doesn’t follow control law because it’s **a nonlinear, second-order plant (or higher), driven by a torque–current mapping that isn’t accurate**, so PID designed for a linear first-order system will struggle. Higher-level control (feedforward, LQR, gain scheduling) is needed to stabilize it.

--- Some other items to consider:

- This video is an ESP32 with github code: [LINK](https://www.youtube.com/watch?v=rpD8mo0Jbuc)
- They aren’t using simple PID.
- With LKF state estimates, they probably use state feedback (like LQR) or PID + feedforward, which can explicitly stabilize second-order dynamics.
- Their robot balances smoothly, while yours oscillates or fails to converge.

# Experiment Plan: Diagnosing Plant Order in Motor Controller System

##  **Diagnose order of the plant**  
1. **Steps**  
   - Apply a step input (setpoint far from actual position) and observe response.  
   - A first-order system shows exponential approach.  
   - A second-order system shows overshoot/ringing.

2. **Burst logging**  
   - Avoid serial output during motion to prevent bottlenecks.  
   - Log data to RAM and dump it only after the test completes.

3. **Setpoint offset**  
   - Start far from the setpoint to create a **clear transient**.  
   - This highlights overshoot, ringing, or divergence.

---

## 📊 What to Record
- **Commanded setpoint** (position or velocity).  
- **Measured position** (encoder).  
- **Velocity estimate** (if available).  
- **Control effort** (torque command or current request).  
- **Phase current feedback** (if available).  
- **Bus voltage / battery voltage** (to catch sag effects).  
- **Error** = setpoint − position.  
- **Optional:** IMU tilt (if balancing robot).  

---

## 🔍 What to Look For
- **First-order behavior:** smooth exponential decay to setpoint, no overshoot.  
- **Second-order behavior:** overshoot, ringing, oscillation before settling.  
- **Nonlinearities:** dead zones, saturation (flat response until torque jumps), current clipping.  
- **Instability:** divergence instead of convergence.  

---

## ⚡ Refinement Ideas
- Run with different step sizes (small vs. large) → nonlinearities will show up if response shape changes.  
- Try with and without load (wheel free vs. on ground).  
- Include a **timestamp or tick counter** in logs to reconstruct dynamics.  

---

## ✅ Conclusion
This experiment will let you see clearly why the plant doesn’t behave like first-order. By analyzing step responses, you can confirm whether the system is **second-order (or higher)** and uncover nonlinearities that break PID control assumptions.

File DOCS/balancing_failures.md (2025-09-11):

# Failure Modes & Watchdogs Checklist

This document lists common issues that can break balancing in the brain board project, along with what to watch for and how to mitigate them.

---

## 1. Model–Reality Gaps
- **Cause:** Wrong mass, inertia, COM height, motor constants, friction, or linearization errors.
- **Watch:** Compare predicted vs measured response, recovery time, deviations from simulation.
- **Mitigation:** Log commanded vs actual response, refine A/B matrices via system identification.

---

## 2. Sensor Problems
- **Cause:** Gyro bias drift, accelerometer noise, encoder quantization.
- **Watch:** Sudden jumps in angle/velocity, gyro bias while stationary, encoder inconsistency.
- **Mitigation:** Log variance/residuals, calibrate IMU, add filtering (complementary/Kalman), use watchdogs for out-of-range values.

---

## 3. Actuator Saturation
- **Cause:** Motors can’t provide commanded torque at high tilt or disturbance.
- **Watch:** Torque command clipping at ±max, battery sag under load.
- **Mitigation:** Log % time saturated, trigger warnings, penalize torque in LQR (larger R), add anti-windup logic.

---

## 4. Timing Jitter & Delays
- **Cause:** Control loop not running exactly at 500 Hz due to blocking I/O or CAN bursts.
- **Watch:** Control loop dt distribution, flag dt > 3–4 ms.
- **Mitigation:** Keep control loop deterministic, throttle telemetry, measure jitter with GPIO/DWT, abort if timing drift exceeds threshold.

---

## 5. Communication Latency / Loss
- **Cause:** CAN congestion, delayed encoder updates, ESP32 UART backpressure.
- **Watch:** Gaps in encoder/velocity updates, node alive status toggling.
- **Mitigation:** Add timeout counters, log packet inter-arrival times, fail safe to idle if CAN stalls.

---

## 6. Estimator Errors
- **Cause:** State estimator provides wrong tilt/velocity due to noise or drift.
- **Watch:** Innovation/residuals (measurement − prediction), divergence in estimated vs measured tilt.
- **Mitigation:** Log innovations, abort if residuals exceed threshold.

---

## 7. Startup Conditions
- **Cause:** Robot starts too tilted (>15°) for linearization to hold.
- **Watch:** Initial tilt angle when enabling balance mode.
- **Mitigation:** Require tilt < 5° before enabling control, otherwise refuse to engage.

---

## 8. Asymmetry & Cross-Coupling
- **Cause:** Left/right motors behave differently, leading to yaw drift.
- **Watch:** Persistent yaw when balancing in place.
- **Mitigation:** Calibrate wheel gains, extend state model to include yaw if necessary.

---

## 9. Physical Robot Issues
- **Frame Flexibility / Looseness**  
  - **Cause:** Weak materials, loose bolts, frame compliance.  
  - **Watch:** Buzzing or oscillation not predicted by model.  
  - **Mitigation:** Rigid frame, thread-lock, stiffening braces.

- **Wheel Slippage**  
  - **Cause:** Low friction tires/surfaces.  
  - **Watch:** Encoder motion without tilt correction.  
  - **Mitigation:** High-friction tires, textured surfaces.

- **Wheel Backlash / Play**  
  - **Cause:** Loose coupling or gears.  
  - **Watch:** Delay between torque and wheel motion.  
  - **Mitigation:** Eliminate play, use direct drive.

- **Asymmetric Hardware**  
  - **Cause:** Unequal wheel/motor behavior.  
  - **Watch:** Constant yaw drift.  
  - **Mitigation:** Match components, calibrate offsets.

- **Center of Mass Shifts**  
  - **Cause:** Payload or battery off-center.  
  - **Watch:** Falls faster than predicted.  
  - **Mitigation:** Keep COM low/centered, secure loads.

- **Structural Resonances**  
  - **Cause:** Flexible members vibrating.  
  - **Watch:** High-frequency IMU oscillations.  
  - **Mitigation:** Stiffen frame, add damping.

- **Loose Encoders / Misalignment**  
  - **Cause:** Poor encoder mount.  
  - **Watch:** Phantom encoder ticks while stationary.  
  - **Mitigation:** Rigid mounting, use Z-index pulse.

- **Electrical / Power Issues**  
  - **Cause:** Loose connectors, voltage sag, brownouts.  
  - **Watch:** Sudden resets, dropouts.  
  - **Mitigation:** Secure wiring, proper gauge, capacitors.

---

# Robustness Strategy
- **Measure:** Collect metrics on dt, saturation, packet loss, sensor bias.
- **Log:** Histograms and distributions to spot drift and load trends.
- **React:** Use thresholds, timeouts, alarms, and safe torque cutoffs.

**Principle:** Anticipate → Instrument → React.

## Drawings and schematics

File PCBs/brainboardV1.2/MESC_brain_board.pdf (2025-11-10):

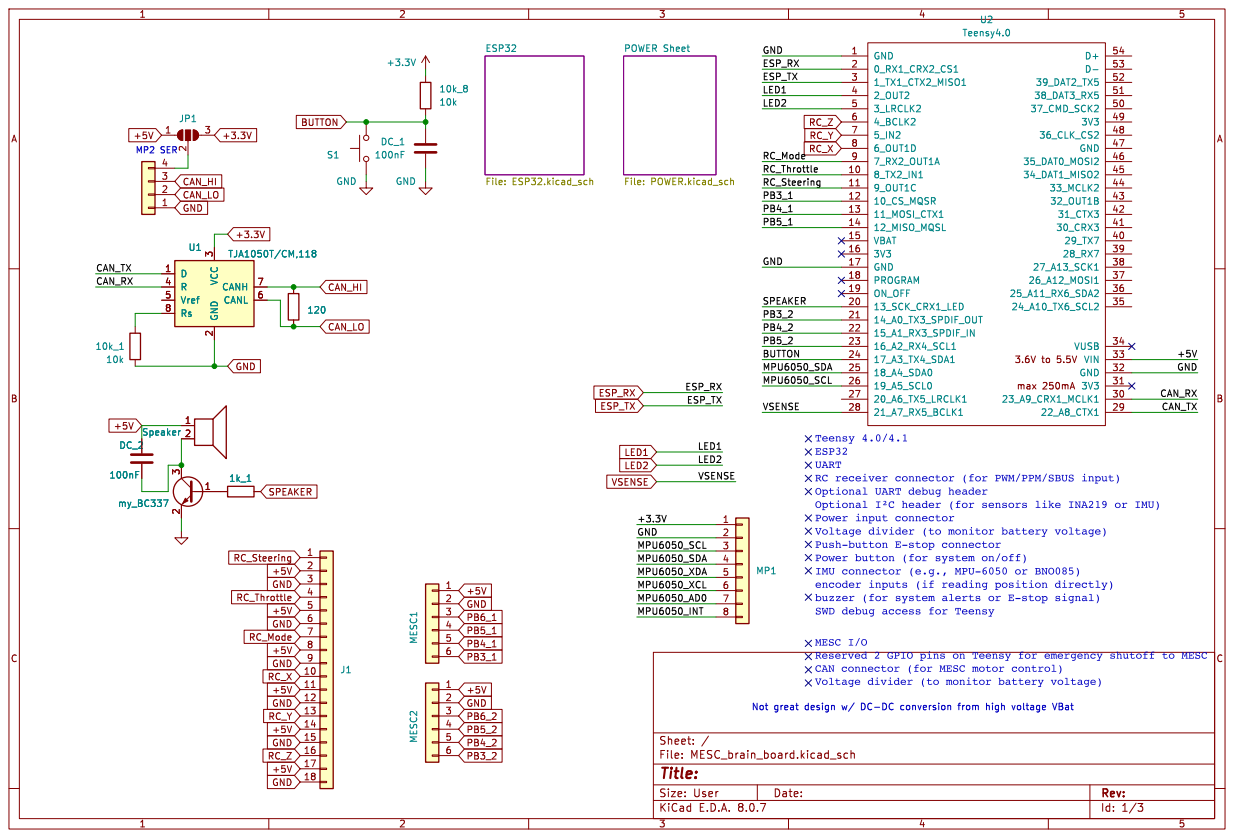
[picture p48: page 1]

Id: 1/3 Title: File: MESC_brain_board.kicad_sch Sheet: /

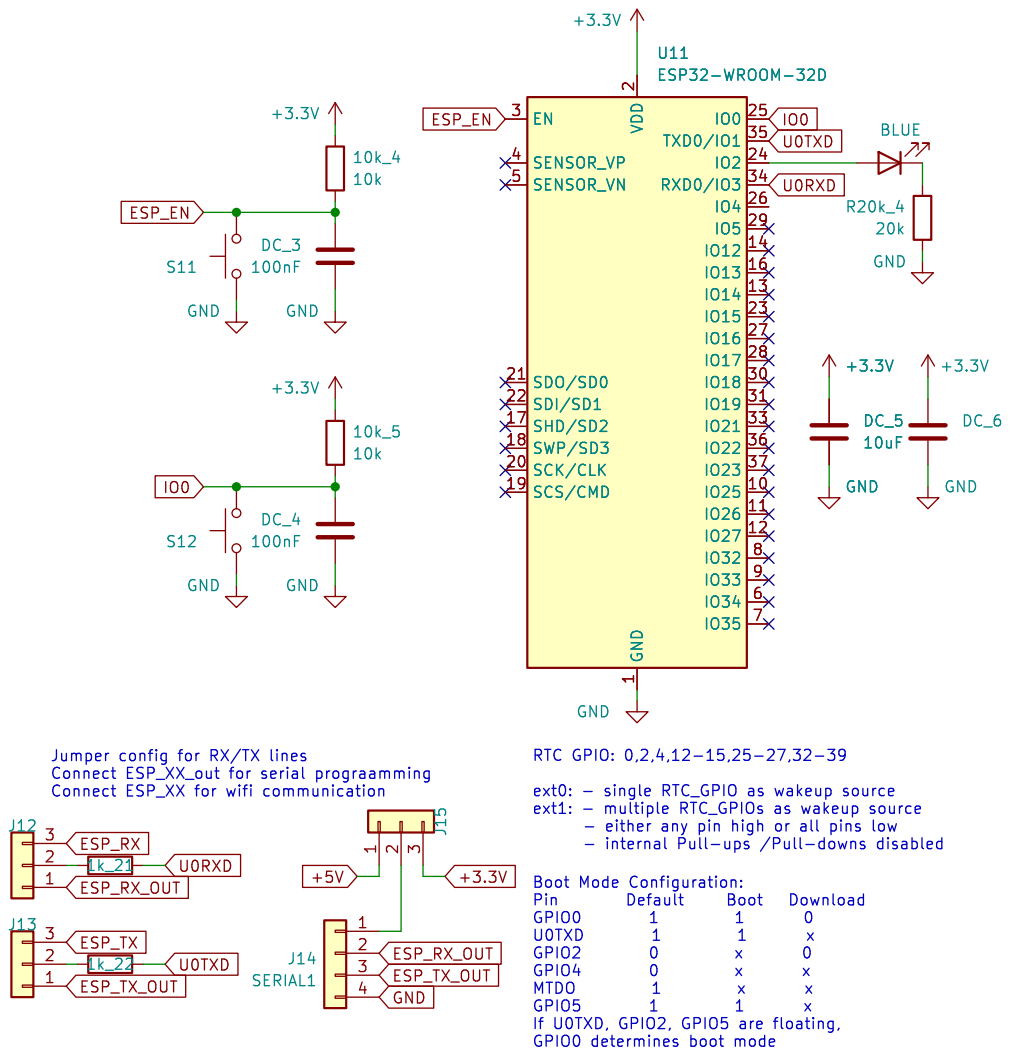
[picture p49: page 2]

ext0: - single RTC_GPIO as wakeup source

https://github.com/CoretechR/OMOTE.git
https://github.com/averywallis/Feather-NEO-M9N-GPS.git

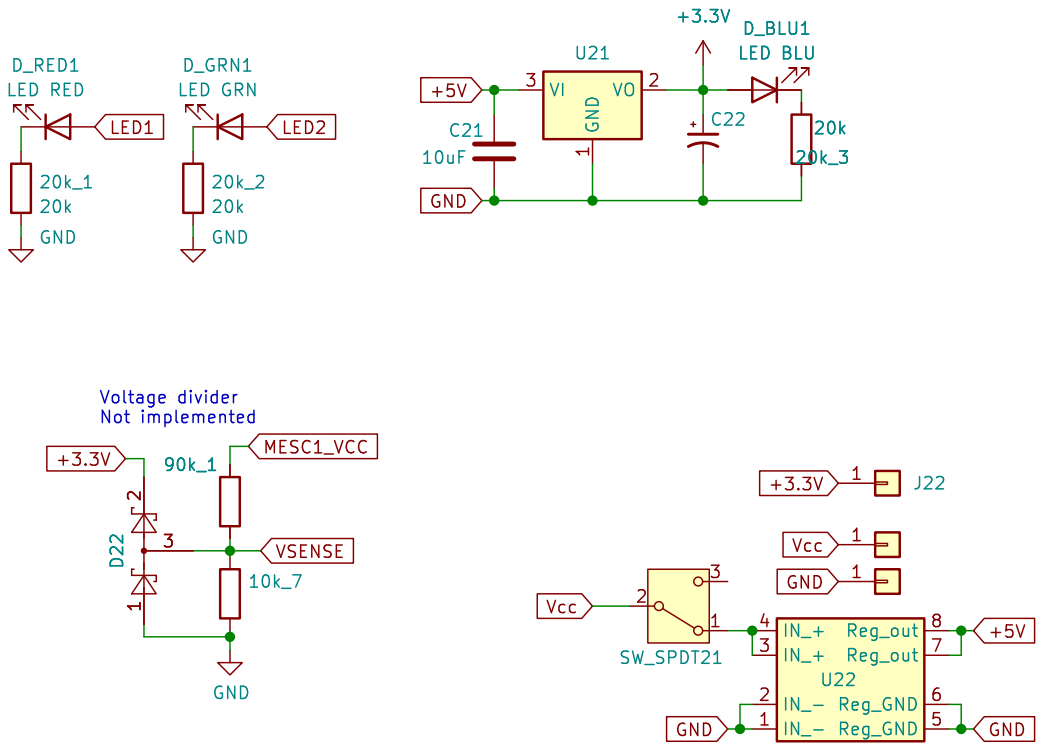
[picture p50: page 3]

Vcc Voltage divider Not implemented D22

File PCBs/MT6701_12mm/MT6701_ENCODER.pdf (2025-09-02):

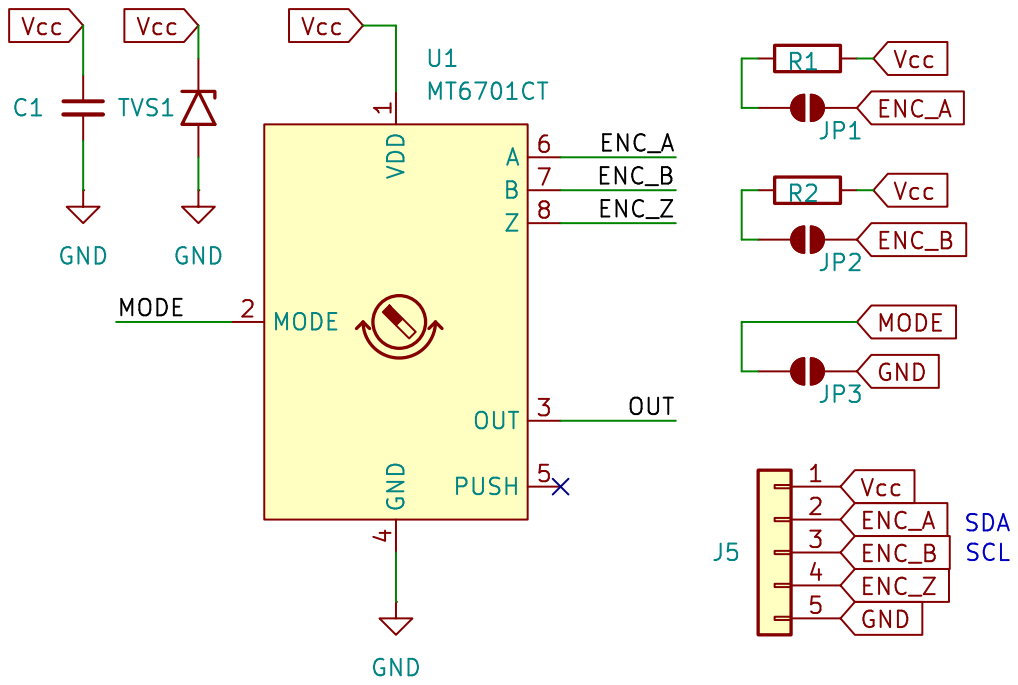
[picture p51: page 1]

Id: 1/1 Title: File: MT6701_ENCODER.kicad_sch Sheet: / GNDVDD

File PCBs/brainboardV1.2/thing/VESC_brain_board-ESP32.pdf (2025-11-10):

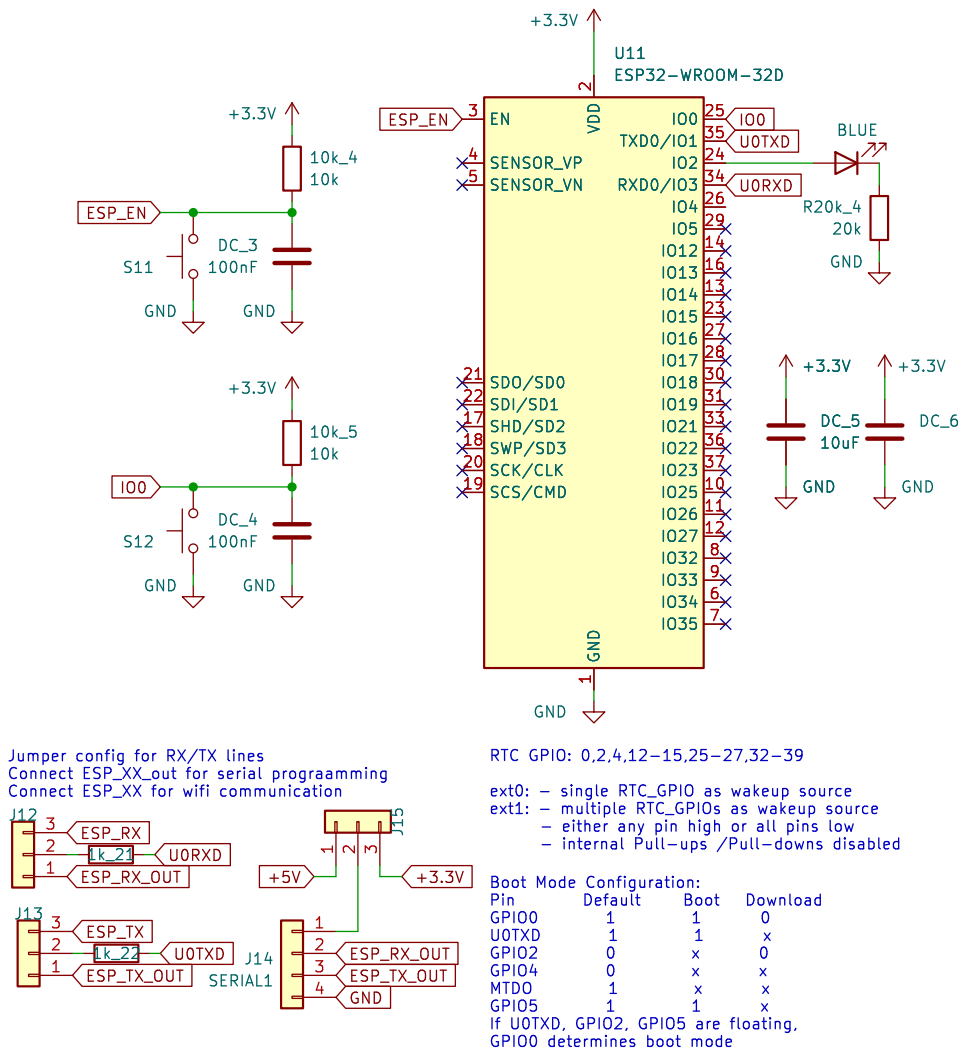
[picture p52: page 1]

ext0: - single RTC_GPIO as wakeup source

https://github.com/CoretechR/OMOTE.git
https://github.com/averywallis/Feather-NEO-M9N-GPS.git

Id: 2/3 Title: File: ESP32.kicad_sch Sheet: /ESP32/

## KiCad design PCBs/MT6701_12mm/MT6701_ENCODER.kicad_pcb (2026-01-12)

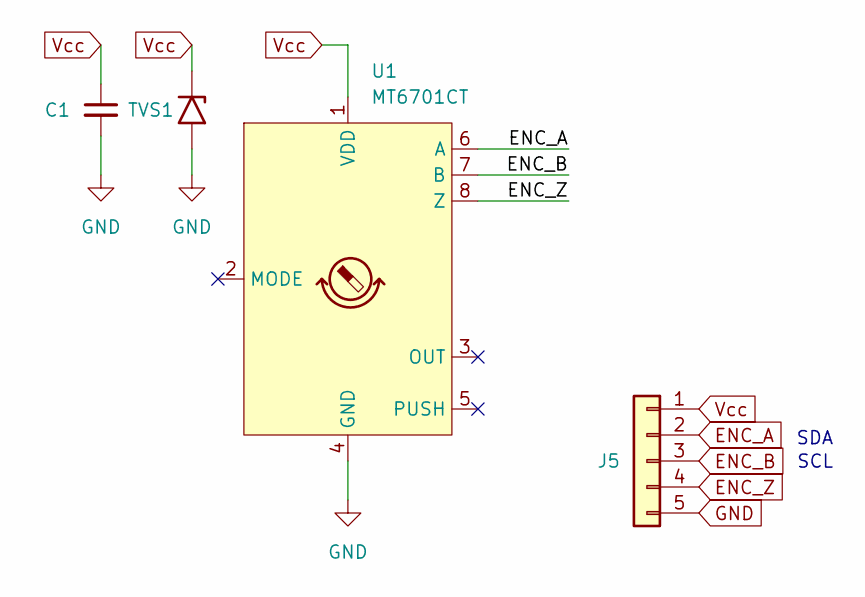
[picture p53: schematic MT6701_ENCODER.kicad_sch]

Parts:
C1: C_Small; C_0603_1608Metric
J5: Conn_01x05; JST_GH_BM05B-GHS-TBT_1x05-1MP_P1.25mm_Vertical
TVS1: SMFJ6.0A / SMFJ6.0CA; C_0805_2012Metric
U1: MT6701CT; SO-8_3.9x4.9mm_P1.27mm

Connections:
ENC_A: J5.2, U1.6 (A)
ENC_B: J5.3, U1.7 (B)
ENC_Z: J5.4, U1.8 (Z)
GND: C1.2, J5.5, TVS1.2 (A2), U1.4 (GND)
Vcc: C1.1, J5.1, TVS1.1 (A1), U1.1 (VDD)

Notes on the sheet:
SDA
SCL

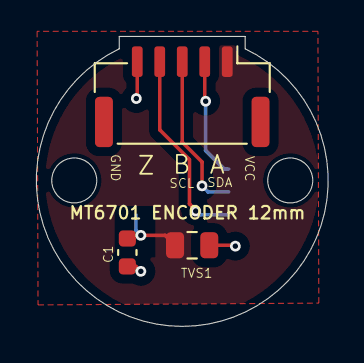
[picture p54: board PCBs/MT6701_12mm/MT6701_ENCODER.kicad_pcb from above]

Board: 2 copper layers, 16.2 x 16.1 mm, 4 parts (1 on the bottom side), 5 nets.

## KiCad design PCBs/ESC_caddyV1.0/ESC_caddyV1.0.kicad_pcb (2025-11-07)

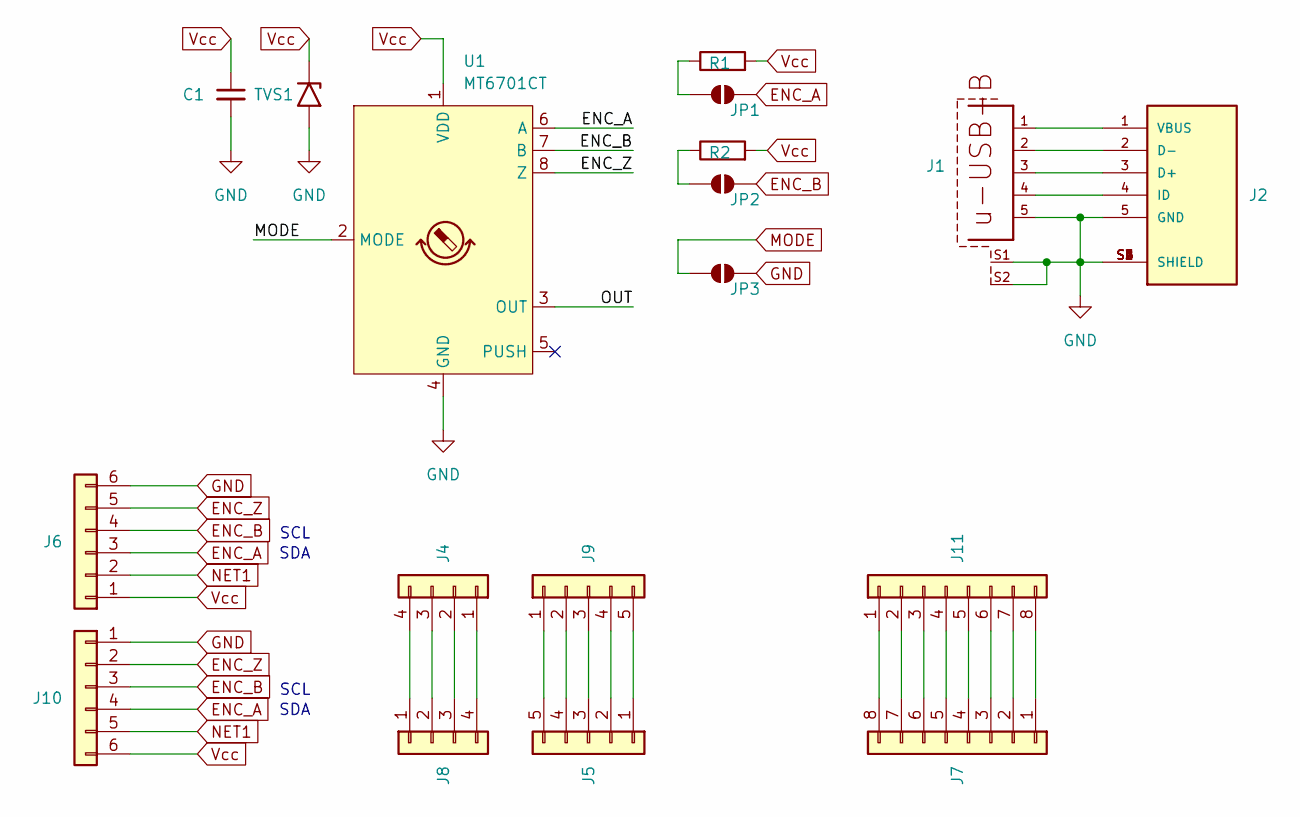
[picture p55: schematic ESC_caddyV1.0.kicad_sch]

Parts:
C1: C_Small; C_0603_1608Metric
J1: USB3145-30-1-A; FARNELL 2311903
J2: USB3150-30-130-A; GCT_USB3150-30-130-A; PARTREV A2
J4, J8: Conn_01x04; JST_PH_B4B-PH-K_1x04_P2.00mm_Vertical
J5, J9: Conn_01x05; JST_PH_B5B-PH-K_1x05_P2.00mm_Vertical
J6, J10: Conn_01x06; JST_PH_B6B-PH-K_1x06_P2.00mm_Vertical
J7, J11: Conn_01x08; JST_PH_B8B-PH-K_1x08_P2.00mm_Vertical
JP1, JP2, JP3: SolderJumper_2_Open; SolderJumper-2_P1.3mm_Open_RoundedPad1.0x1.5mm
R1, R2: R; R_0603_1608Metric
TVS1: SMFJ6.0A / SMFJ6.0CA; C_0805_2012Metric
U1: MT6701CT; SO-8_3.9x4.9mm_P1.27mm

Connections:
/OUT: U1.3 (OUT)
ENC_A: J6.3, J10.4, JP1.2 (B), U1.6 (A)
ENC_B: J6.4, J10.3, JP2.2 (B), U1.7 (B)
ENC_Z: J6.5, J10.2, U1.8 (Z)
GND: C1.2, J1.5, J1.S1, J1.S2, J2.5 (GND), J2.S1 (SHIELD), J2.S2 (SHIELD), J2.S3 (SHIELD), J2.S4 (SHIELD), J2.S5 (SHIELD), J2.S6 (SHIELD), J6.6, J10.1, JP3.2 (B), TVS1.2 (A2), U1.4 (GND)
MODE: JP3.1 (A), U1.2 (MODE)
NET1: J6.2, J10.5
unnamed: J1.3, J2.3 (D+)
unnamed: J1.2, J2.2 (D-)
unnamed: J1.4, J2.4 (ID)
unnamed: J1.1, J2.1 (VBUS)
unnamed: J4.1, J8.4
unnamed: J4.2, J8.3
unnamed: J4.3, J8.2
unnamed: J4.4, J8.1
unnamed: J5.1, J9.5
unnamed: J5.2, J9.4
unnamed: J5.3, J9.3
unnamed: J5.4, J9.2
unnamed: J5.5, J9.1
unnamed: J7.8, J11.1
unnamed: J7.7, J11.2
unnamed: J7.6, J11.3
unnamed: J7.5, J11.4
unnamed: J7.4, J11.5
unnamed: J7.3, J11.6
unnamed: J7.2, J11.7
unnamed: J7.1, J11.8
unnamed: JP1.1 (A), R1.1
unnamed: JP2.1 (A), R2.1
Vcc: C1.1, J6.1, J10.6, R1.2, R2.2, TVS1.1 (A1), U1.1 (VDD)

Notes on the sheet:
SCL
SDA

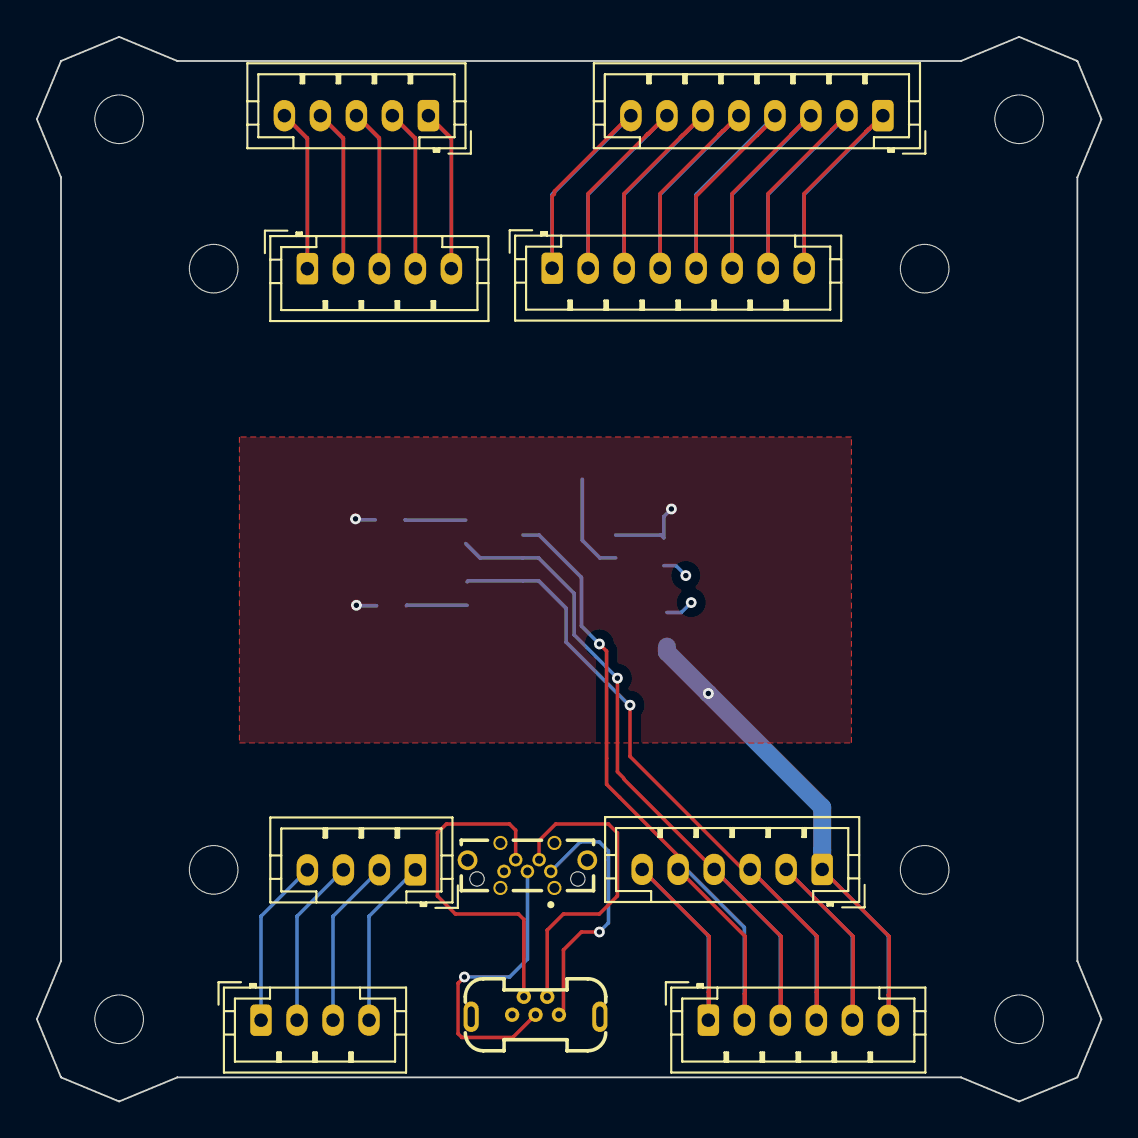
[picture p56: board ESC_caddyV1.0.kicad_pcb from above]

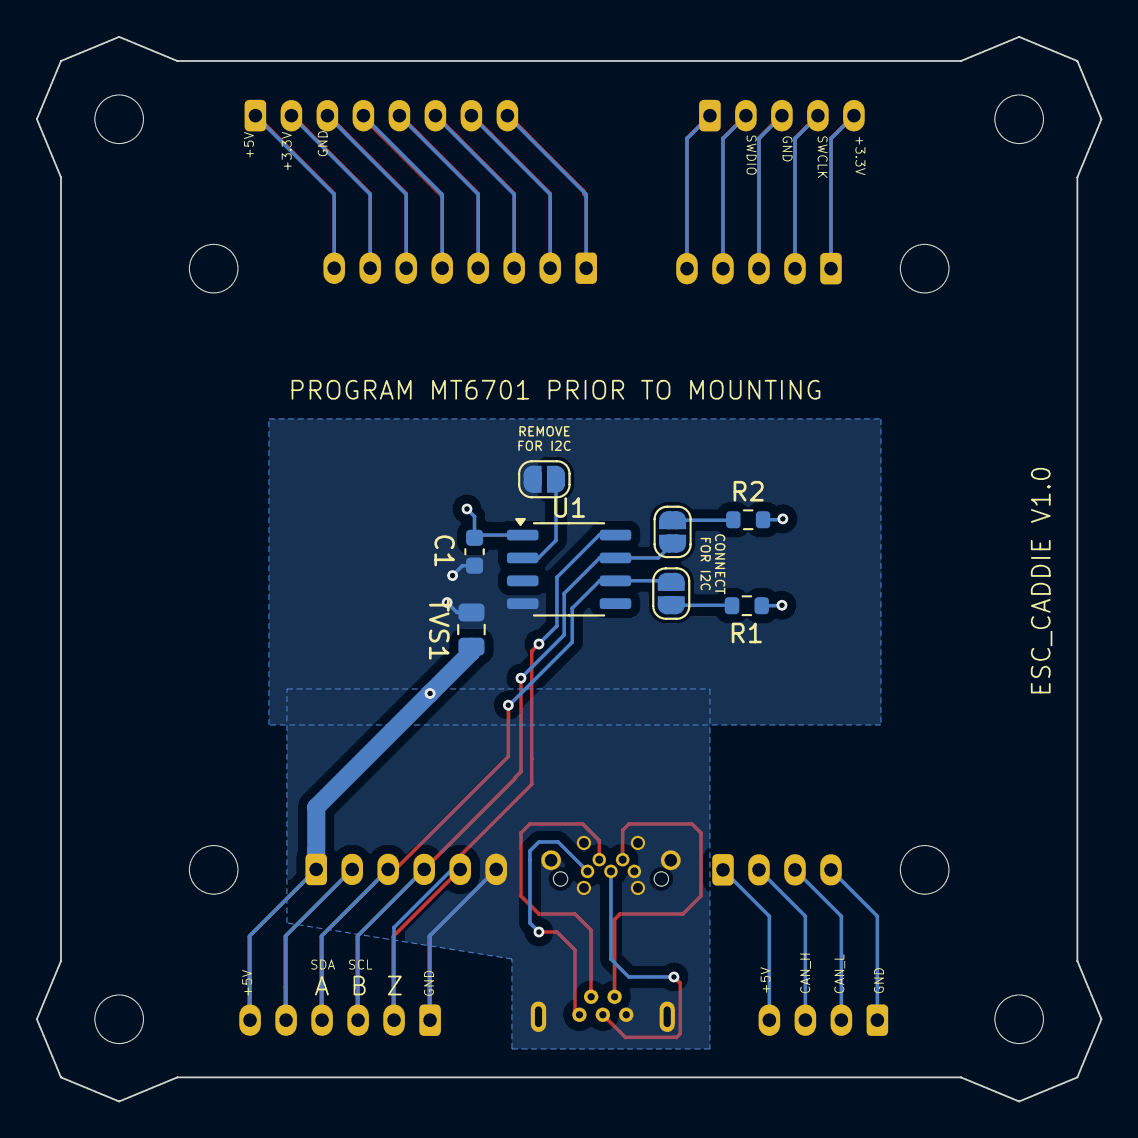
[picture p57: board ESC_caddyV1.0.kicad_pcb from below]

Board: 2 copper layers, 59.1 x 59.1 mm, 18 parts (8 on the bottom side), 30 nets.

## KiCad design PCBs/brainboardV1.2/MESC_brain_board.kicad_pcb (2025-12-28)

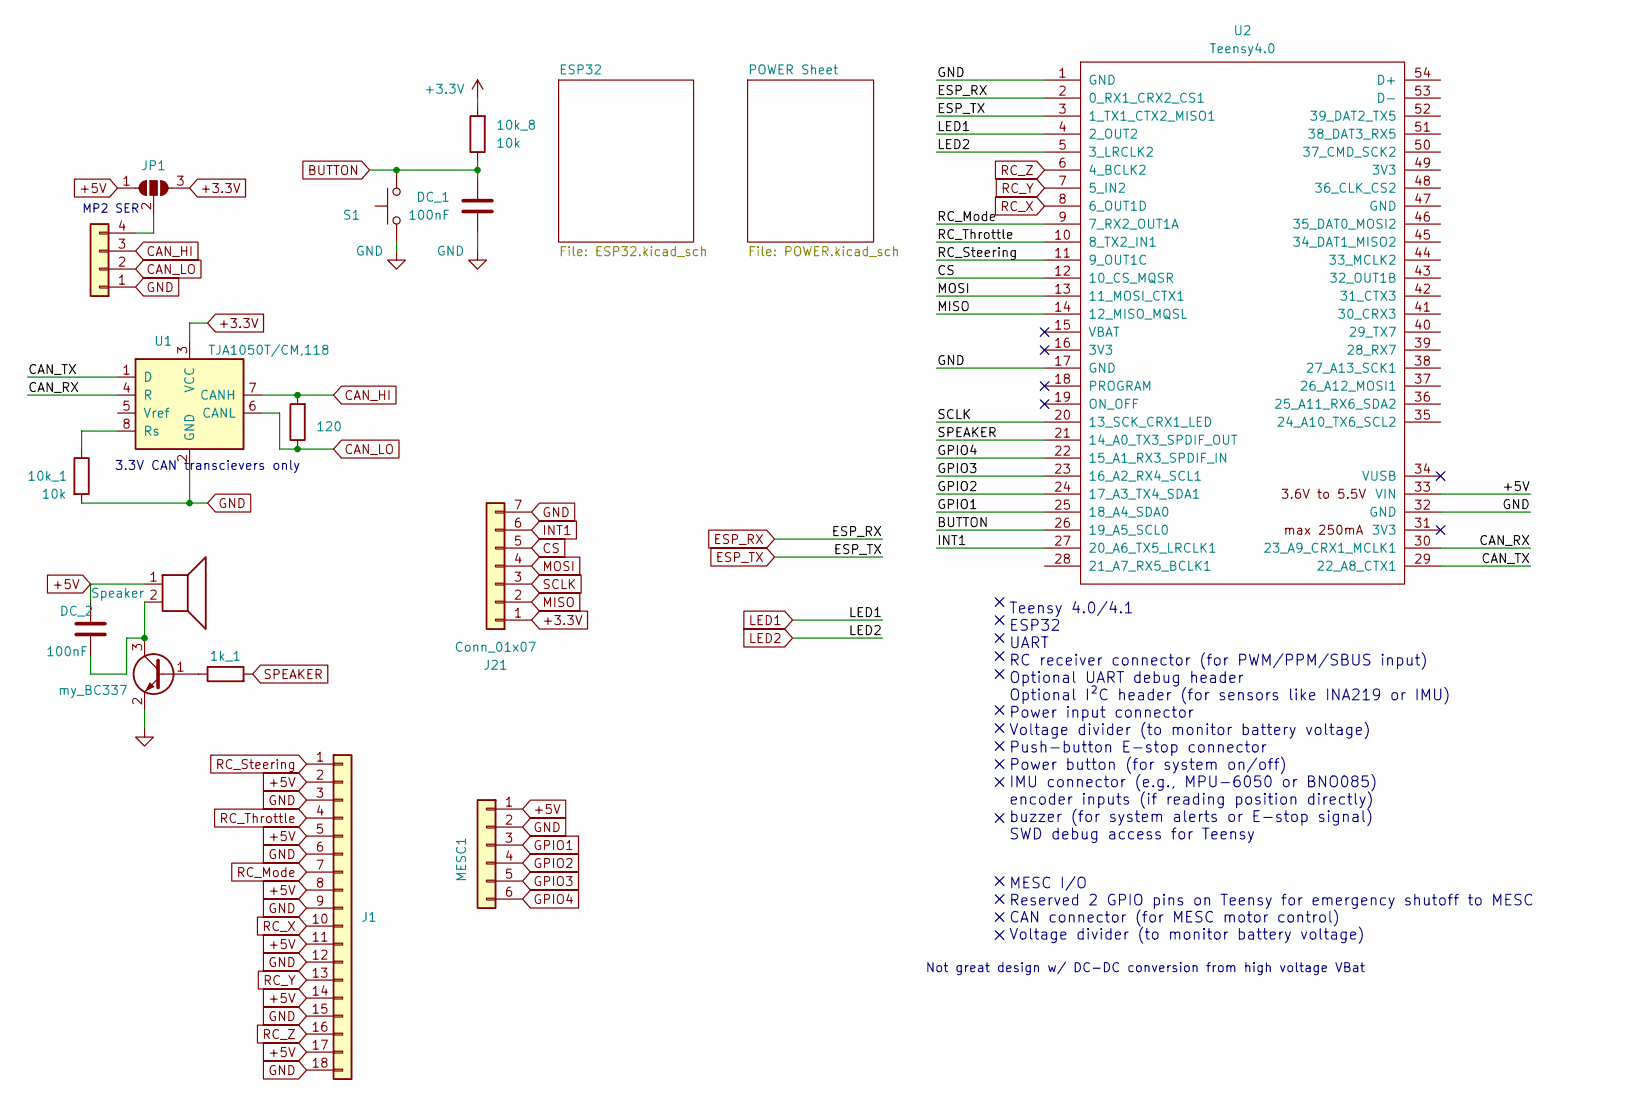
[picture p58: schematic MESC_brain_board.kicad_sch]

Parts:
1k_1: 10k; R_0603_1608Metric
10k_1, 10k_8: 10k; R_0603_1608Metric; LCSC C25804
CAN1: Conn_01x04; JST_PH_B4B-PH-K_1x04_P2.00mm_Vertical
DC_1: 100nF; C_0603_1608Metric; LCSC C14663
DC_2: 100nF; C_0603_1608Metric
J1: Conn_01x18; my_PinSocket_3x07_P2.54mm_Vertical
J21: Conn_01x07; JST_PH_B7B-PH-K_1x07_P2.00mm_Vertical
JP1: SolderJumper_3_Open; SolderJumper-3_P1.3mm_Open_Pad1.0x1.5mm
LS1: Speaker; SPKR_CDS-13138-SMT-TR
MESC1: Conn_01x06; JST_PH_B6B-PH-K_1x06_P2.00mm_Vertical
Q1: my_BC337; SOT-23
R_120: 120; R_0603_1608Metric; LCSC C17437
S1: TL3342F160QG; SW_SPST_B3SL-1022P; LCSC C318884
U1: TJA1050T/CM,118; SOIC-8_3.9x4.9mm_P1.27mm; LCSC C6952
U2: Teensy4.0; Teensy40

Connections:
+3.3V: 10k_8.2, J21.1, JP1.3 (B), U1.3 (VCC); also elsewhere on the board
+5V: DC_2.1, J1.2, J1.5, J1.8, J1.11, J1.14, J1.17, JP1.1 (A), LS1.1, MESC1.1, U2.33 (VIN); also elsewhere on the board
/CAN_RX: U1.4 (R), U2.30 (23_A9_CRX1_MCLK1)
/CAN_TX: U1.1 (D), U2.29 (22_A8_CTX1)
BUTTON: 10k_8.1, DC_1.2, S1.2, U2.26 (19_A5_SCL0)
CAN_HI: CAN1.3, R_120.2, U1.7 (CANH)
CAN_LO: CAN1.2, R_120.1, U1.6 (CANL)
CS: J21.5, U2.12 (10_CS_MQSR)
ESP_RX: U2.2 (0_RX1_CRX2_CS1); also elsewhere on the board
ESP_TX: U2.3 (1_TX1_CTX2_MISO1); also elsewhere on the board
GND: 10k_1.2, CAN1.1, DC_1.1, J1.3, J1.6, J1.9, J1.12, J1.15, J1.18, J21.7, MESC1.2, Q1.2 (E), S1.1, U1.2 (GND), U2.1 (GND), U2.17 (GND), U2.32 (GND); also elsewhere on the board
GPIO1: MESC1.3, U2.25 (18_A4_SDA0)
GPIO2: MESC1.4, U2.24 (17_A3_TX4_SDA1)
GPIO3: MESC1.5, U2.23 (16_A2_RX4_SCL1)
GPIO4: MESC1.6, U2.22 (15_A1_RX3_SPDIF_IN)
INT1: J21.6, U2.27 (20_A6_TX5_LRCLK1)
LED1: U2.4 (2_OUT2); also elsewhere on the board
LED2: U2.5 (3_LRCLK2); also elsewhere on the board
MISO: J21.2, U2.14 (12_MISO_MQSL)
MOSI: J21.4, U2.13 (11_MOSI_CTX1)
unnamed: CAN1.4, JP1.2 (C)
unnamed: 1k_1.1, Q1.1 (B)
unnamed: DC_2.2, LS1.2, Q1.3 (C)
unnamed: 10k_1.1, U1.8 (Rs)
RC_Mode: J1.7, U2.9 (7_RX2_OUT1A)
RC_Steering: J1.1, U2.11 (9_OUT1C)
RC_Throttle: J1.4, U2.10 (8_TX2_IN1)
RC_X: J1.10, U2.8 (6_OUT1D)
RC_Y: J1.13, U2.7 (5_IN2)
RC_Z: J1.16, U2.6 (4_BCLK2)
SCLK: J21.3, U2.20 (13_SCK_CRX1_LED)
SPEAKER: 1k_1.2, U2.21 (14_A0_TX3_SPDIF_OUT)

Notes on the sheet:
Teensy 4.0/4.1 ESP32 UART RC receiver connector (for PWM/PPM/SBUS input) Optional UART debug header Optional I²C header (for sensors like INA219 or IMU) Power input connector Voltage divider (to monitor battery voltage) Push-button E-stop connector Power button (for system on/off) IMU connector (e.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
MP2 SER
MESC I/O Reserved 2 GPIO pins on Teensy for emergency shutoff to MESC CAN connector (for MESC motor control) Voltage divider (to monitor battery voltage)
3.3V CAN transcievers only
Not great design w/ DC-DC conversion from high voltage VBat

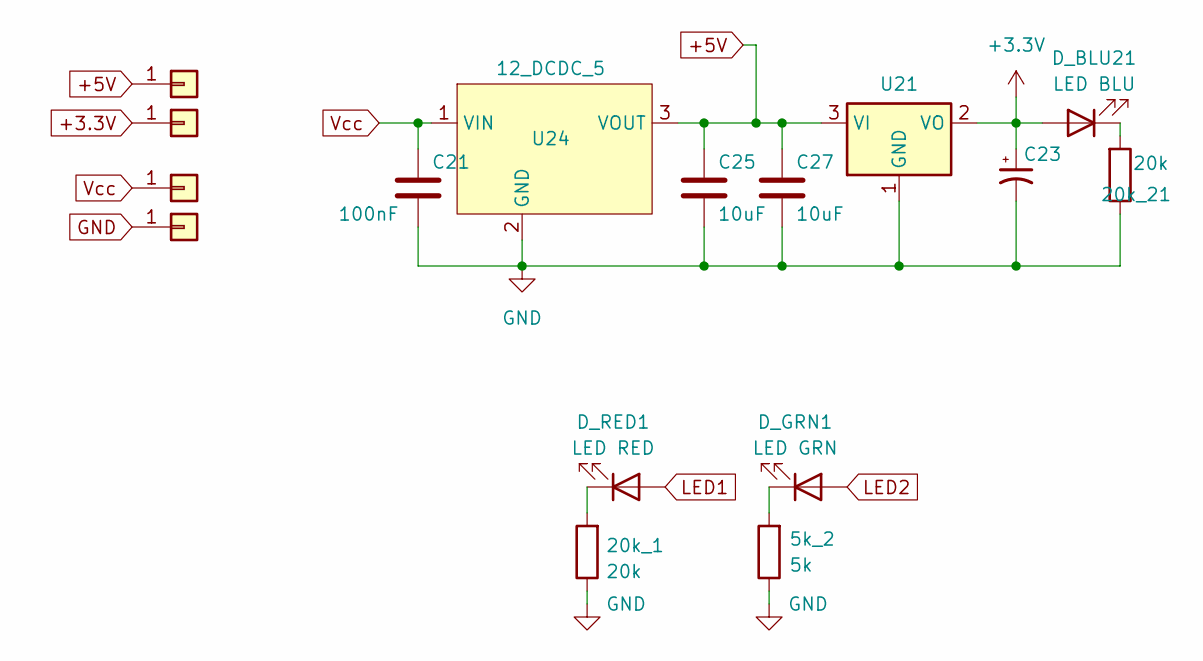
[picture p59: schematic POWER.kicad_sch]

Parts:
5k_2: 5k; R_0603_1608Metric; LCSC C4184
20k_1, 20k_21: 20k; R_0603_1608Metric; LCSC C4184
C21: 100nF; C_0805_2012Metric; LCSC C342865
C23: C_Polarized_Small_US; CP_EIA-3216-18_Kemet-A; LCSC C7171
C25, C27: 10uF; C_0805_2012Metric; LCSC C96446
D_BLU21: LED BLU; LED_0603_1608Metric; LCSC C72041
D_GRN1: LED GRN; LED_0603_1608Metric; LCSC C72043
D_RED1: LED RED; LED_0603_1608Metric; LCSC C2286
J22, J23: Conn_01x01; PinSocket_1x01_P2.54mm_Vertical
J24, J25: Conn_01x01; SolderWire-2sqmm_1x01_D2mm_OD3.9mm
U21: LD1117S18TR_SOT223; SOT-223-3_TabPin2; LCSC C2984862
U24: 12_DCDC_5

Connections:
+3.3V: C23.1, D_BLU21.2 (A), J22.1, U21.2 (VO); also elsewhere on the board
+5V: C25.1, C27.1, J23.1, U21.3 (VI), U24.3 (VOUT); also elsewhere on the board
GND: 5k_2.1, 20k_1.1, 20k_21.1, C21.2, C23.2, C25.2, C27.2, J24.1, U21.1 (GND), U24.2 (GND); also elsewhere on the board
LED1: D_RED1.2 (A); also elsewhere on the board
LED2: D_GRN1.2 (A); also elsewhere on the board
unnamed: 20k_21.2, D_BLU21.1 (K)
unnamed: 5k_2.2, D_GRN1.1 (K)
unnamed: 20k_1.2, D_RED1.1 (K)
Vcc: C21.1, J25.1, U24.1 (VIN)

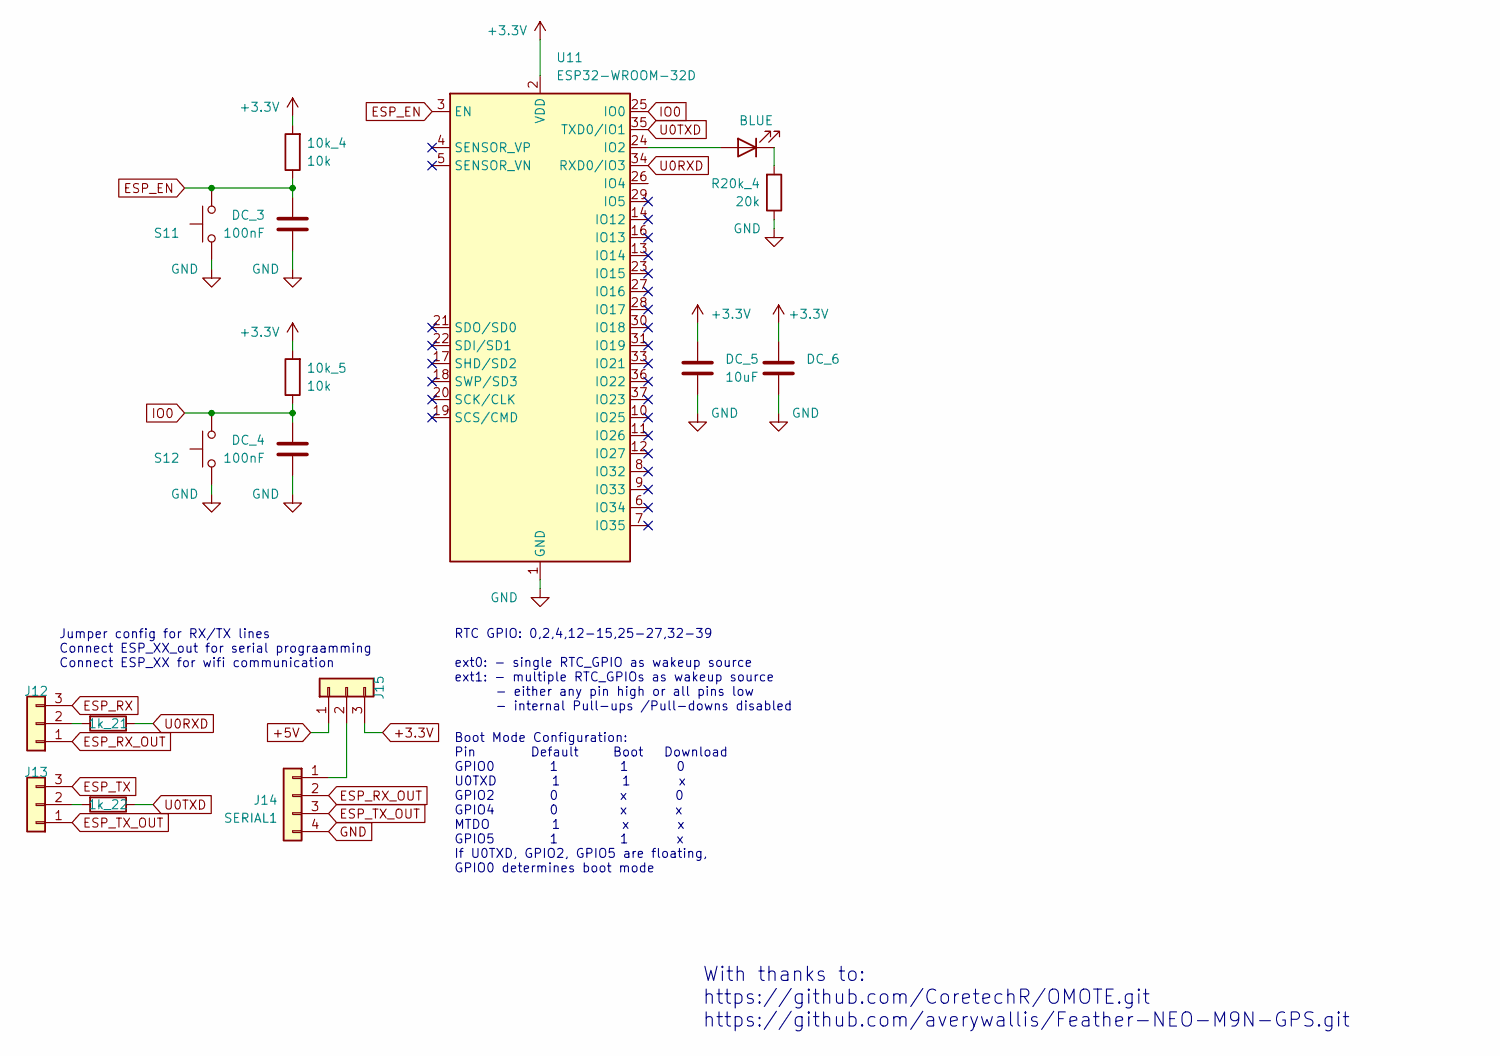
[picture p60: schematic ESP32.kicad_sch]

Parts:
1k_21, 1k_22: 1k; R_0603_1608Metric; LCSC C25804
10k_4, 10k_5: 10k; R_0603_1608Metric; LCSC C25804
DC_3, DC_4, DC_6: 100nF; C_0603_1608Metric; LCSC C14663
DC_5: 10uF; C_0805_2012Metric; LCSC C15850
D_BLU2: BLUE; LED_0603_1608Metric; LCSC C72041
J12, J13, J15: Conn_01x03; PinHeader_1x03_P2.54mm_Vertical
J14: SERIAL1; PinHeader_1x04_P2.54mm_Vertical
R20k_4: 20k; R_0603_1608Metric; LCSC C4184
S11, S12: TL3342F160QG; SW_Push_SPST_NO_Alps_SKRK; LCSC C318884
U11: ESP32-WROOM-32D; LCSC C529578

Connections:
+3.3V: 10k_4.2, 10k_5.2, DC_5.2, DC_6.1, J15.3, U11.2 (VDD); also elsewhere on the board
+5V: J15.1; also elsewhere on the board
ESP_EN: 10k_4.1, DC_3.2, S11.2, U11.3 (EN)
ESP_RX: J12.3; also elsewhere on the board
ESP_RX_OUT: J12.1, J14.2
ESP_TX: J13.3; also elsewhere on the board
ESP_TX_OUT: J13.1, J14.3
GND: DC_3.1, DC_4.1, DC_5.1, DC_6.2, J14.4, R20k_4.1, S11.1, S12.1, U11.1 (GND), U11.15 (GND), U11.38 (GND), U11.39 (GND); also elsewhere on the board
IO0: 10k_5.1, DC_4.2, S12.2, U11.25 (IO0)
unnamed: D_BLU2.2 (A), U11.24 (IO2)
unnamed: D_BLU2.1 (K), R20k_4.2
unnamed: 1k_21.2, J12.2
unnamed: 1k_22.2, J13.2
unnamed: J14.1, J15.2
U0RXD: 1k_21.1, U11.34 (RXD0/IO3)
U0TXD: 1k_22.1, U11.35 (TXD0/IO1)

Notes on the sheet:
Boot Mode Configuration: Pin Default Boot Download GPIO0 1 1 0 U0TXD 1 1 x GPIO2 0 x 0 GPIO4 0 x x MTDO 1 x x GPIO5 1 1 x If U0TXD, GPIO2, GPIO5 are floating, GPIO0 determines boot mode
Jumper config for RX/TX lines Connect ESP_XX_out for serial prograamming Connect ESP_XX for wifi communication
With thanks to: https://github.com/CoretechR/OMOTE.git https://github.com/averywallis/Feather-NEO-M9N-GPS.git
RTC GPIO: 0,2,4,12-15,25-27,32-39 ext0: - single RTC_GPIO as wakeup source ext1: - multiple RTC_GPIOs as wakeup source - either any pin high or all pins low - internal Pull-ups /Pull-downs disabled

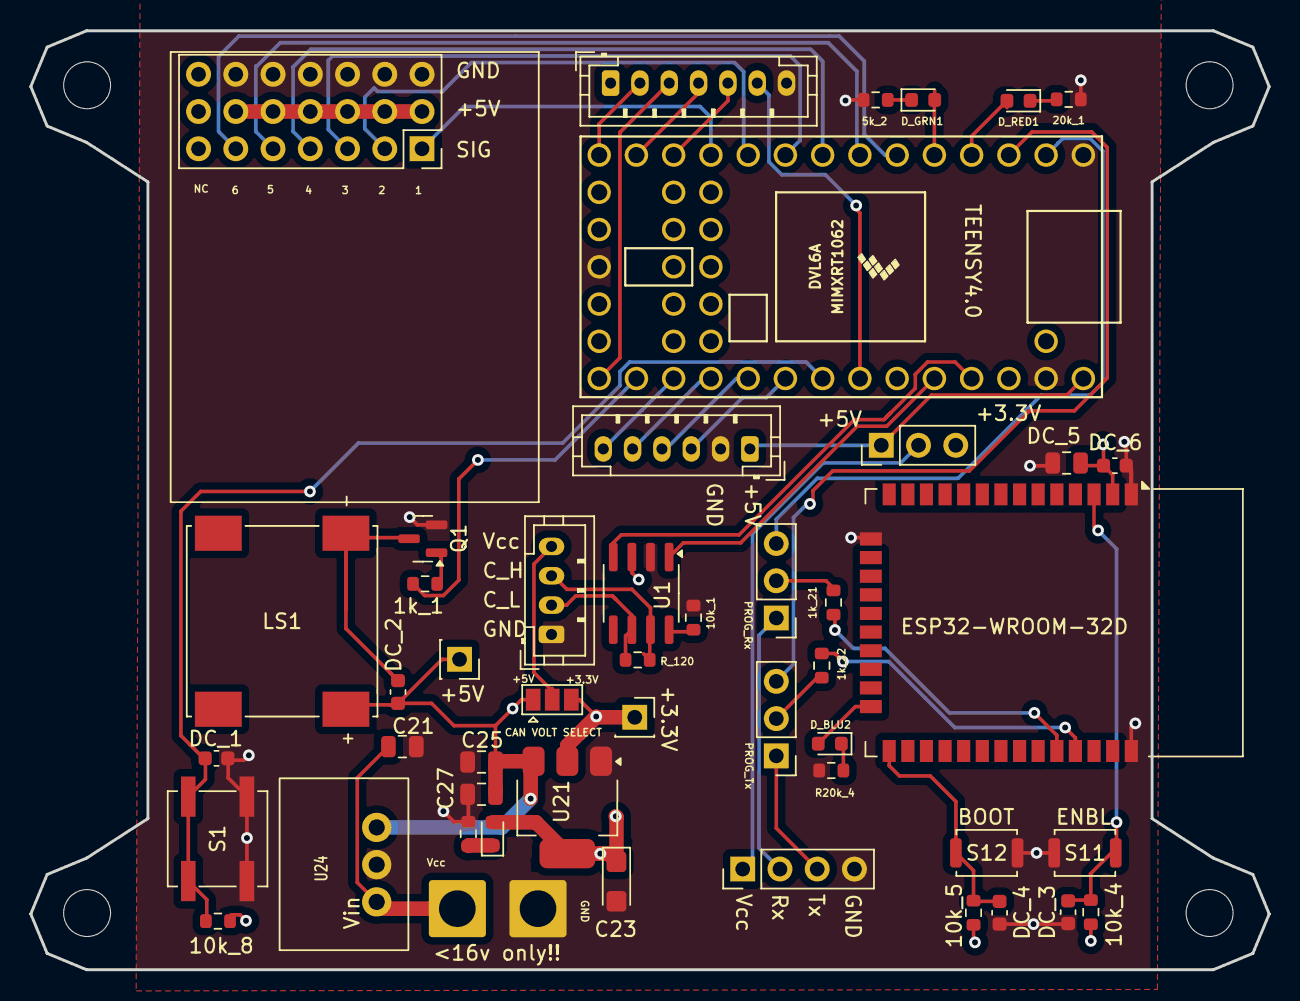
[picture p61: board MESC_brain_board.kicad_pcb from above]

Board: 4 copper layers, 84.5 x 64.0 mm, 49 parts (0 on the bottom side), 47 nets.

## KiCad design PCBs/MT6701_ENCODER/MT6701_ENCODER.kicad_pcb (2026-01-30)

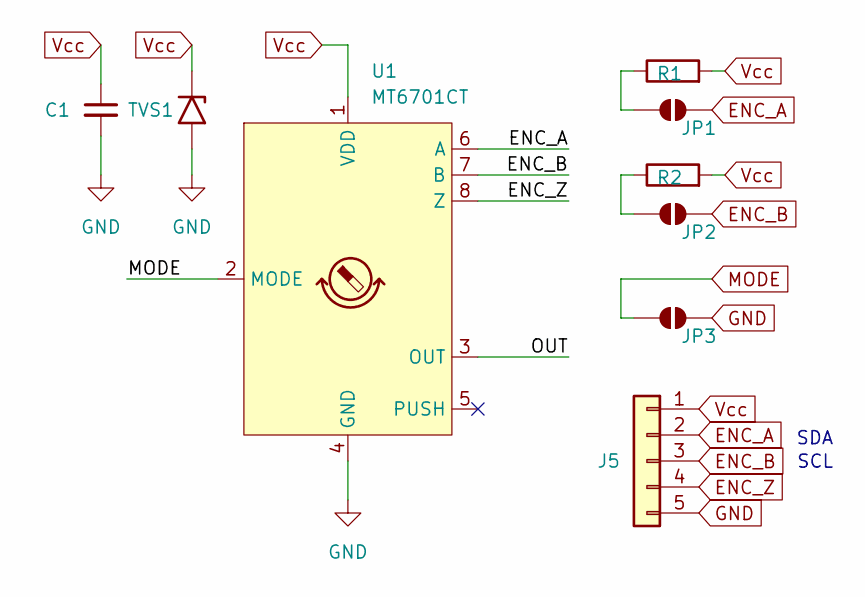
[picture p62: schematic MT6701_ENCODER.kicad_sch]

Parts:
C1: C_Small; C_0603_1608Metric
J5: Conn_01x05; PinHeader_1x05_P2.54mm_Vertical
JP1, JP2, JP3: SolderJumper_2_Open; SolderJumper-2_P1.3mm_Open_RoundedPad1.0x1.5mm
R1, R2: R; R_0603_1608Metric
TVS1: SMFJ6.0A / SMFJ6.0CA; C_0805_2012Metric
U1: MT6701CT; SO-8_3.9x4.9mm_P1.27mm

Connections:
/OUT: U1.3 (OUT)
ENC_A: J5.2, JP1.2 (B), U1.6 (A)
ENC_B: J5.3, JP2.2 (B), U1.7 (B)
ENC_Z: J5.4, U1.8 (Z)
GND: C1.2, J5.5, JP3.2 (B), TVS1.2 (A2), U1.4 (GND)
MODE: JP3.1 (A), U1.2 (MODE)
unnamed: JP1.1 (A), R1.1
unnamed: JP2.1 (A), R2.1
Vcc: C1.1, J5.1, R1.2, R2.2, TVS1.1 (A1), U1.1 (VDD)

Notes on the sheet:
SDA
SCL

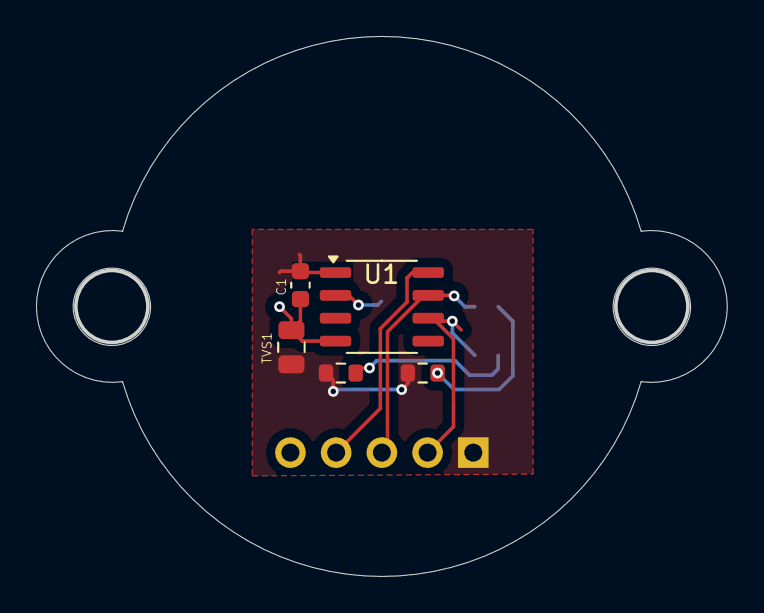
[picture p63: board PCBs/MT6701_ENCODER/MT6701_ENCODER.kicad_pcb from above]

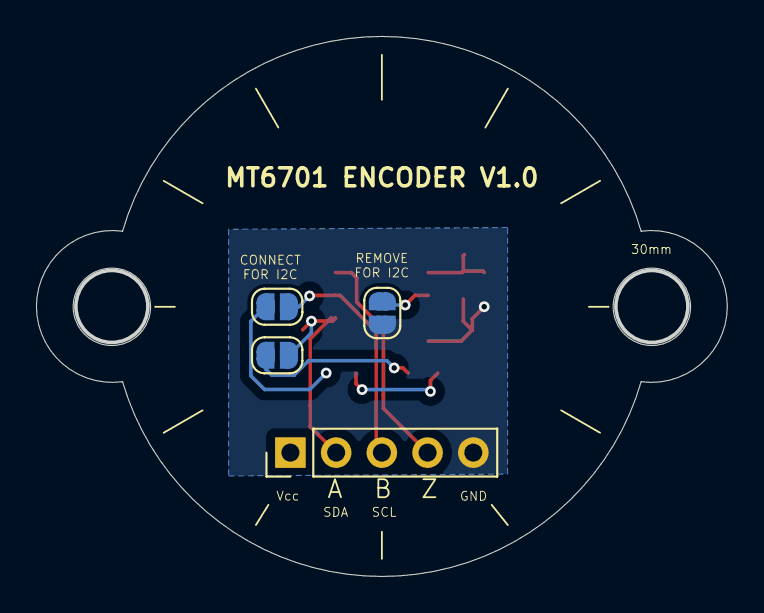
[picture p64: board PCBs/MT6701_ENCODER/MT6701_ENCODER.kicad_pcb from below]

Board: 4 copper layers, 38.4 x 30.0 mm, 9 parts (4 on the bottom side), 8 nets.

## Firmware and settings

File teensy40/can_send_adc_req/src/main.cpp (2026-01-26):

#include <Arduino.h>
#include <FlexCAN_T4.h>

// === Teensy CAN setup ===
FlexCAN_T4<CAN1, RX_SIZE_256, TX_SIZE_16> Can1;

#define PUSHBUTTON_PIN 17
#define LED_PIN 2

// MESC CAN ID for Iq request
#define CAN_ID_IQREQ   0x001
#define CAN_ID_POSVEL  0x2D0   // MESC POS/VEL ID

// IDs
#define TEENSY_NODE_ID  0x03   // sender (this Teensy)
#define ESC_NODE_ID1    0x0B   // receiver (your ESC node_id = 11)
#define ESC_NODE_ID2    0x0C   // receiver (your ESC node_id = 12)

float max_current = 4.0f;

// --- Ring buffer for safe message passing ---
const int BUF_SIZE = 32;
CAN_message_t rxBuf[BUF_SIZE];
volatile int head = 0, tail = 0;

// ===== RX LED "flash while traffic" logic =====
// We want visible flashing even at high CAN rates.
// Strategy:
// - On ANY received frame, arm an "active" window into the future.
// - While active, blink at a human-visible rate (e.g., 5 Hz).
// - Do NOT use delay() for blinking; we service it every loop.

static const uint32_t LED_ACTIVE_MS   = 500;  // keep blinking this long after last RX frame
static const uint32_t LED_TOGGLE_MS   = 100;  // 100ms toggle => 5 Hz blink
static volatile uint32_t led_active_until_ms = 0;

static inline void noteCanRxActivity() {
  uint32_t now = millis();
  led_active_until_ms = now + LED_ACTIVE_MS;
}

bool bufferPush(const CAN_message_t &msg) {
  int next = (head + 1) % BUF_SIZE;
  if (next == tail) return false; // buffer full, drop
  rxBuf[head] = msg;
  head = next;
  return true;
}

bool bufferPop(CAN_message_t &msg) {
  if (head == tail) return false; // empty
  msg = rxBuf[tail];
  tail = (tail + 1) % BUF_SIZE;
  return true;
}

// --- POSVEL handler ---
void handlePosVel(const CAN_message_t &msg) {
  uint8_t receiver = (msg.id) & 0xFF; // receiver ID (per your packing)

  if (msg.len == 8) {
    float pos, vel;
    uint32_t u0 = (uint32_t)msg.buf[0] |
                  ((uint32_t)msg.buf[1] << 8) |
                  ((uint32_t)msg.buf[2] << 16) |
                  ((uint32_t)msg.buf[3] << 24);
    uint32_t u1 = (uint32_t)msg.buf[4] |
                  ((uint32_t)msg.buf[5] << 8) |
                  ((uint32_t)msg.buf[6] << 16) |
                  ((uint32_t)msg.buf[7] << 24);
    memcpy(&pos, &u0, sizeof(float));
    memcpy(&vel, &u1, sizeof(float));

    Serial.printf("{\"t_us\":%lu,\"sender\":%u,\"pos\":%.6f,\"vel\":%.6f}\r\n",
                  micros(), receiver, pos, vel);
  }
}

// --- General CAN handler ---
void canHandler(const CAN_message_t &msg) {
  uint16_t mid = (msg.id >> 16) & 0x1FFF; // unpack MESC message ID
  if (mid == CAN_ID_POSVEL) {
    handlePosVel(msg);
  }
}

// Build full 29-bit CAN extended ID
uint32_t make_ext_id(uint16_t msg_id, uint8_t sender, uint8_t receiver) {
  return ((uint32_t)msg_id << 16) |
         ((uint32_t)receiver << 8) |
         sender;
}

// Encode float into buffer
void pack_float(float val, uint8_t *buf) {
  memcpy(buf, &val, sizeof(float));
}

static bool running = false; // motion enabled flag

void setup() {
  Serial.begin(115200);
  while (!Serial && millis() < 2000) {}

  pinMode(PUSHBUTTON_PIN, INPUT_PULLUP);

  pinMode(LED_PIN, OUTPUT);
  digitalWriteFast(LED_PIN2, HIGH);

  Serial.println("Press any key to toggle motion START/STOP.");

  delay(2000);

  Can1.begin();
  Can1.setBaudRate(500000);

  // If you only use extended frames, you can optionally add:
  // Can1.setMBFilter(REJECT_ALL);
  // Can1.setMBFilter(ACCEPT_ALL, 0);  // depends on your FlexCAN_T4 usage
}

// #define LOOP1 0
#define LOOP2 1
// #define LOOP3 0

#if LOOP2
void loop() {
  static uint8_t state = 0;              // 0=idle, 1=forward, 2=idle, 3=reverse
  static uint32_t last_switch_ms = 0;
  const uint32_t STATE_HOLD_MS = 400;

  // Non-blocking send pacing (replaces delay(100))
  static uint32_t last_send_ms = 0;
  const uint32_t SEND_PERIOD_MS = 100;

  // Service LED every loop (non-blocking)
  // serviceRxLed();

  // --- Serial toggle control ---
  if (Serial.available()) {
    (void)Serial.read(); // clear the key
    running = !running;
    Serial.printf("Motion %s\r\n", running ? "STARTED" : "STOPPED");
    // no delay() debounce; if you want one, do a simple time-gate instead
  }

  // --- Drain CAN RX FIFO quickly ---
  CAN_message_t msg;
  while (Can1.read(msg)) {
    noteCanRxActivity();  // <-- activity latch (any received frame)
    bufferPush(msg);
  }

  // --- Process buffered frames ---
  while (bufferPop(msg)) {
    canHandler(msg);
  }

  // Rate-limit CAN TX without blocking loop
  uint32_t now_ms = millis();
  if (now_ms - last_send_ms < SEND_PERIOD_MS) {
    return;
  }
  last_send_ms = now_ms;

  if (!running) {
    // --- Send zero torque (stop command) to both ESCs ---
    float cmd = 0.0f;
    for (int i = 0; i < 2; i++) {
      uint16_t esc_id = (i == 0) ? ESC_NODE_ID1 : ESC_NODE_ID2;
      CAN_message_t tx;
      tx.id = make_ext_id(CAN_ID_IQREQ, TEENSY_NODE_ID, esc_id);
      tx.flags.extended = 1;
      tx.len = 8;
      pack_float(cmd, tx.buf);
      float zero = 0.0f;
      pack_float(zero, tx.buf + 4);
      Can1.write(tx);
      Serial.printf("STOP: Sent Iq_req=%.3f A to ESC node_id=%u (CAN ID=0x%08X)\r\n",
                    cmd, esc_id, tx.id);
    }
    return;
  }

  // --- State machine: advance every STATE_HOLD_MS ---
  if (now_ms - last_switch_ms >= STATE_HOLD_MS) {
    last_switch_ms = now_ms;
    state = (state + 1) % 4;
  }

  // --- Command selection based on state ---
  float cmd = 0.0f;
  if (state == 0)       cmd =  0.0f;
  else if (state == 1)  cmd =  max_current;
  else if (state == 2)  cmd =  0.0f;
  else if (state == 3)  cmd = -max_current;

  // --- Clamp safety range ---
  if (cmd > 10.0f)  cmd = 10.0f;
  if (cmd < -10.0f) cmd = -10.0f;

  // --- Send to both ESCs ---
  for (int i = 0; i < 2; i++) {
    uint16_t esc_id = (i == 0) ? ESC_NODE_ID1 : ESC_NODE_ID2;
    CAN_message_t tx;
    tx.id = make_ext_id(CAN_ID_IQREQ, TEENSY_NODE_ID, esc_id);
    tx.flags.extended = 1;
    tx.len = 8;
    pack_float(cmd, tx.buf);
    float zero = 0.0f;
    pack_float(zero, tx.buf + 4);
    Can1.write(tx);

    Serial.printf("State %u: Sent Iq_req=%.3f A to ESC node_id=%u (CAN ID=0x%08X)\r\n",
                  state, cmd, esc_id, tx.id);
  }
}
#endif

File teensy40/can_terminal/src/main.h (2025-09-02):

#ifndef MAIN_H
#define MAIN_H

#include <Arduino.h>
#include <IntervalTimer.h>
#include <FlexCAN_T4.h>

// ================= Pins from your board =================
#define LED1_PIN        2
#define LED2_PIN        3
#define PUSHBUTTON_PIN  17
#define SPEAKER_PIN     13

// ================= RC PWM (4 channels) =================
#define RC_CH_COUNT     4
#define RC_INPUT1       9
#define RC_INPUT2       8
#define RC_INPUT3       7
#define RC_INPUT4       6

#define CAN_TX          24
#define CAN_RX          25

// ================= Control loop timing =================
#ifndef CONTROL_HZ
#define CONTROL_HZ      1000u                 // 1 kHz control loop
#endif
#define CONTROL_PERIOD_US (1000000u / CONTROL_HZ)

// ================= CAN config =================
// NOTE: Verify which CAN controller maps to your 24/25 pins on Teensy 4.0.
// Many shields use CAN2 for that pair. Change CAN_CONTROLLER to CAN1/CAN3 if needed.
#define CAN_CONTROLLER  CAN2
#ifndef CAN_BITRATE
#define CAN_BITRATE     1000000u              // 1 Mbit/s CAN 2.0
#endif

// ================= Types =================
typedef struct {
  uint32_t id;
  uint8_t  len;
  uint8_t  buf[8];
  uint32_t t_us;     // timestamp when captured
} CanFrame;

// Your control math (called at CONTROL_HZ, outside the ISR)
void control_step(uint32_t now_us);

#endif // MAIN_H

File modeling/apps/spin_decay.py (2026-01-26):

#!/usr/bin/env python3
import sys
import serial
import json
import matplotlib.pyplot as plt
import numpy as np
import argparse

"""
Spin-down capture + decay fit (single sender)

- Assumes baud rate = 115200
- Uses ONLY sender 11
- Assumes logging rate = 500 Hz (dt = 0.002 s)
- Wait until |vel| >= START_SPEED_RAD_S, then record until |vel| <= STOP_SPEED_RAD_S
- Fits exponential: |ω(t)| ≈ ω0 * exp(-t/τ)
- Calculates and displays:
    τ [s]
    b/J = 1/τ [1/s]
    If J provided: b = J/τ [N·m·s/rad]
    Drag torque at selected speeds: τ_drag(ω) = b*ω  (or (b/J)*ω if J not provided)
    Power at selected speeds: P(ω) = b*ω^2         (or (b/J)*ω^2 per J)

Optional:
- Also fits a 2-term model for windage:
    J dω/dt = -(b ω + c ω^2)
  reporting c if fit is possible and J is provided (units: N·m·s^2/rad^2).
"""

SENDER_ID = 11
BAUD = 115200

LOG_HZ = 500.0
DT = 1.0 / LOG_HZ

START_SPEED_RAD_S = 100.0
STOP_SPEED_RAD_S = 0.5
OMEGA_MIN_FIT_RAD_S = 5.0  # exclude low-speed region (Coulomb / quantization)

MAX_CAPTURE_SAMPLES = 2_000_000


def safe_float(x, default=None):
    try:
        if x is None:
            return default
        return float(x)
    except (TypeError, ValueError):
        return default


def fit_exponential_decay(t_s, omega_rad_s, omega_min_fit=OMEGA_MIN_FIT_RAD_S):
    """
    Fit ln(|omega|) = a + s*t over data:
      - only after peak |omega| (true spin-down)
      - only where |omega| >= omega_min_fit

    Returns: tau_s, slope_s, r2, fit_mask (mask into original arrays used for fit)
    """
    t0 = np.asarray(t_s, dtype=float)
    w0 = np.abs(np.asarray(omega_rad_s, dtype=float))

    valid = np.isfinite(t0) & np.isfinite(w0) & (w0 > 0)
    if np.count_nonzero(valid) < 30:
        return None, None, None, None

    # Work in the "valid" reduced arrays, but keep a mapping back to original indices
    idx_valid = np.where(valid)[0]
    t = t0[idx_valid]
    w = w0[idx_valid]

    # After peak only
    i_peak = int(np.argmax(w))
    idx_after_peak = idx_valid[i_peak:]   # original indices after peak
    t_ap = t0[idx_after_peak]
    w_ap = w0[idx_after_peak]

    if len(t_ap) < 30:
        return None, None, None, None

    # Fit region within after-peak
    fit_local = np.isfinite(t_ap) & np.isfinite(w_ap) & (w_ap >= float(omega_min_fit))
    if np.count_nonzero(fit_local) < 30:
        return None, None, None, None

    t_fit = t_ap[fit_local]
    w_fit = w_ap[fit_local]

    y = np.log(w_fit)

    # Linear least squares: y = a + s*t
    A = np.vstack([np.ones_like(t_fit), t_fit]).T
    (a, s), *_ = np.linalg.lstsq(A, y, rcond=None)

    # R^2
    y_hat = a + s * t_fit
    ss_res = np.sum((y - y_hat) ** 2)
    ss_tot = np.sum((y - np.mean(y)) ** 2)
    r2 = 1.0 - ss_res / ss_tot if ss_tot > 0 else None

    if s >= 0:
        return None, s, r2, None

    tau = -1.0 / s

    # Build fit_mask in original array coordinates
    fit_mask = np.zeros_like(t0, dtype=bool)
    fit_mask[idx_after_peak[fit_local]] = True

    return tau, s, r2, fit_mask


def fit_two_term_drag(t_s, omega_rad_s):
    """
    Fit dω/dt = -a ω - k ω^2  (where a = b/J and k = c/J)
    using least squares on the spin-down region.
    Returns: a, k, r2
    """
    t = np.asarray(t_s, dtype=float)
    w = np.abs(np.asarray(omega_rad_s, dtype=float))

    if len(t) < 50:
        return None, None, None

    # Use only after peak and above a threshold
    i_peak = int(np.argmax(w))
    t = t[i_peak:]
    w = w[i_peak:]
    mask = (w >= max(OMEGA_MIN_FIT_RAD_S, 5.0)) & np.isfinite(w) & np.isfinite(t)
    t = t[mask]
    w = w[mask]
    if len(t) < 50:
        return None, None, None

    # Numerical derivative (simple, but OK at 500 Hz if data is reasonably smooth)
    # Use central differences
    dt = np.diff(t)
    if np.any(dt <= 0):
        return None, None, None

    dw = np.diff(w)
    w_mid = 0.5 * (w[:-1] + w[1:])
    t_mid = 0.5 * (t[:-1] + t[1:])
    wdot = dw / dt  # dω/dt

    # Model: -wdot = a*w + k*w^2
    y = -wdot
    X = np.vstack([w_mid, w_mid**2]).T

    # Least squares
    coeff, *_ = np.linalg.lstsq(X, y, rcond=None)
    a, k = coeff[0], coeff[1]

    y_hat = X @ coeff
    ss_res = np.sum((y - y_hat) ** 2)
    ss_tot = np.sum((y - np.mean(y)) ** 2)
    r2 = 1.0 - ss_res / ss_tot if ss_tot > 0 else None

    return a, k, r2


def main():
    parser = argparse.ArgumentParser()
    parser.add_argument("port", help="Serial port, e.g. /dev/ttyUSB0 or COM5")
    parser.add_argument(
        "--J",
        type=float,
        default=None,
        help="Flywheel inertia in kg*m^2. If provided, b = J/τ and c = J*k are reported.",
    )
    args = parser.parse_args()

    ser = serial.Serial(args.port, BAUD, timeout=1)
    print(f"Opened {args.port} at {BAUD} baud. Listening for sender {SENDER_ID}...")
    print(f"Assumed logging rate: {LOG_HZ:.0f} Hz (dt={DT:.6f} s)")
    print(f"START when |vel| >= {START_SPEED_RAD_S} rad/s")
    print(f"STOP  when |vel| <= {STOP_SPEED_RAD_S} rad/s\n")

    omega = []
    t_s = []

    started = False
    sample_idx = 0

    while True:
        line = ser.readline().decode(errors="ignore").strip()
        if not line:
            continue

        try:
            msg = json.loads(line)
        except json.JSONDecodeError:
            continue

        if msg.get("sender", None) != SENDER_ID:
            continue

        v = safe_float(msg.get("vel", None))
        if v is None:
            continue

        if not started:
            if abs(v) >= START_SPEED_RAD_S:
                started = True
                print(f"✅ START capture at sample {sample_idx} (|vel|={abs(v):.2f} rad/s)")
            else:
                continue

        omega.append(v)
        t_s.append(sample_idx * DT)
        sample_idx += 1

        if sample_idx >= MAX_CAPTURE_SAMPLES:
            print("⚠️ Reached MAX_CAPTURE_SAMPLES safety cap. Stopping.")
            break

        if abs(v) <= STOP_SPEED_RAD_S:
            print(f"✅ STOP  capture at sample {sample_idx} (|vel|={abs(v):.2f} rad/s)")
            break

    ser.close()

    if len(omega) < 100:
        print("Not enough data captured to fit reliably. Try a longer spin-down.")
        return

    # --- Exponential fit ---
    tau_s, slope, r2, fit_mask = fit_exponential_decay(t_s, omega, omega_min_fit=OMEGA_MIN_FIT_RAD_S)
    b_over_J = (1.0 / tau_s) if (tau_s is not None and tau_s > 0) else None
    b = (args.J / tau_s) if (args.J is not None and tau_s is not None and tau_s > 0) else None

    # --- Optional two-term fit (windage) ---
    a, k, r2_2term = fit_two_term_drag(t_s, omega)  # a=b/J, k=c/J
    c = (args.J * k) if (args.J is not None and k is not None) else None

    # --- Plot (velocity only) ---
    fig, ax = plt.subplots(1, 1, figsize=(10, 6))
    ax.set_title("Spin-down velocity capture (sender 11)")
    ax.set_xlabel("Time [s]")
    ax.set_ylabel("Velocity ω [rad/s]")
    ax.grid(True)

    t_arr = np.asarray(t_s, dtype=float)
    w_arr = np.asarray(omega, dtype=float)
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

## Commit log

2025-08-31 added jitter documentation
2025-09-07 minor changes
    [MESC_brain_board.kicad_sch]
2025-09-20 documenting PID issues
2025-09-21 finally got PID working. See PID_fail folder
2025-09-28 added modeling folder
    [aluminum.stl, housing.stl, neodynium.stl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]
2025-09-30 added more documentation
    [pendulum.3dm, pendulum.urdf]
2025-09-30 testing STLs
    [aluminum.stl, housing.stl, neodynium.stl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]
2025-09-30 modeling scripts
    [aluminum.stl, housing.stl, neodynium.stl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]
2025-10-02 prep for torque response
2025-10-10 created new STL->URDF generator
2025-10-12 finished first experiments raising pendulum
    [neodynium.stl, pendulum2.3dm, pendulum_assembly.urdf]
2025-10-22 completed LQI position control of motor
2025-10-29 LQR modeling of balance bot
    [ESC.stl, aluminum.stl, battery.stl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]
2025-11-05 working out IMU issues
    [can_posvel_read.py, main.cpp, main.h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]
2025-11-07 designed ESC caddy
    [ESC_caddyV1.0-B_Cu.dxf, ESC_caddyV1.0-B_Mask.dxf, ESC_caddyV1.0-B_Paste.dxf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]
2025-11-08 IMU testing
    [MT6701_ENCODER-B_Cu.dxf, MT6701_ENCODER-B_Mask.dxf, MT6701_ENCODER-B_Paste.dxf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]
2025-11-10 started on brain board v1.2
    [ESP32.kicad_sch, MESC_brain_board-B_Cu.dxf, MESC_brain_board-B_Mask.dxf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]
2025-11-10 finalizing brain board v1.2
    [MESC_brain_board-B_Cu.dxf, MESC_brain_board-B_Mask.dxf, MESC_brain_board-B_Silkscreen.dxf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]
2025-11-12 documentation stuff
    [MESC_brain_board-B_Cu.dxf, MESC_brain_board-B_Mask.dxf, MESC_brain_board-B_Silkscreen.dxf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]
2025-11-23 vibration reduction / filtering
    [main.cpp]
2025-12-28 BLDC inductance measurement
    [ESP32.kicad_sch, MESC_brain_board.kicad_pcb, MESC_brain_board.kicad_sch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]
2026-01-12 created MT6701_12mm
    [MT6701_ENCODER-B_Cu.dxf, MT6701_ENCODER-B_Mask.dxf, MT6701_ENCODER-B_Paste.dxf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]
2026-01-12 Update motor parameters format in motor_deets.3dm
    [motor_deets.3dm]
2026-01-12 Fix formatting of motor details headings
2026-01-12 Remove redundant set parameters from motor details
2026-01-12 Format motor parameters in motor_deets.md
2026-01-12 Add QS165 V2 parameters to motor_deets.md
2026-01-20 more wood robot design
    [wood.stl]
2026-01-23 refactoring modeling directory
    [ESC.stl, battery.stl, battery_clamp.stl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]
2026-01-28 worked on generate_TWR_data.py
    [ESC.stl, battery.stl, connector.stl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]
2026-01-30 worked on DOCs
    [ESC_caddyV1.0-B_Cu.dxf, ESC_caddyV1.0-B_Mask.dxf, ESC_caddyV1.0-B_Paste.dxf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]
